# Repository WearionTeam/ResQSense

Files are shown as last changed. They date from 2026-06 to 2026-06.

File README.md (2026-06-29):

 # ResQSense

**ResQSense** is a smart vest project designed to protect those who give everything for us: firefighters. The system monitors vital signs, detects falls, and tracks the user's location in real time, sending all data over radio using **LoRa** technology (essential for scenarios without internet or mobile network coverage).

## Repository Structure

* **Documentation:** Project reports, test logs, and explanations of how the algorithms work (such as Man-Down and PDR).
* **Management:** Project organization and our Gantt chart template for tracking deadlines.
* **Schematics:** Hardware electrical schematics (native KiCad files and PDF versions for direct viewing on GitHub).
* **firmware:** Contains the C++ code. Includes test examples (UWB, vitals reading, etc.) and the final project divided into two parts: the vest (**vest**) and the central hub (**dashboard-tablet**).
* **shared:** Stores the global configuration files (`config.h` and `protocol.h`) that define the hardware pins and the data packet structure.
    * **Important Note:** This folder is only required for the vest's firmware (**vest**). It was created separately and mapped in the `platformio.ini` file to cleanly share definitions, but it is not used in any other project code (such as the dashboard or tablet).

## Main Vest Features

* **Fall Detection (Man-Down):** The IMU (MPU-6050) detects free falls and impacts. If the user remains immobile, it triggers an SOS.
* **Vital Signs:** Heart rate and blood oxygen (SpO2) measurement, along with a fault-tolerant system featuring 3 temperature sensors (TMP117).
* **Hybrid Navigation:** Uses GPS/GNSS, but if the signal is lost (e.g., inside a pavilion), it uses IMU steps to estimate the position.
* **Custom TDMA LoRa Network:** We created a time-slotted LoRa network (TDMA) to allow multiple vests to communicate with the central hub without packet collisions, featuring AES-128 encryption.

## How to run the Vest Code

The software project was developed using **PlatformIO**. To test or upload the code to the board:

1. Install [Visual Studio Code](https://code.visualstudio.com/) and the **PlatformIO** extension.
2. Clone this repository to your PC:
   ```bash
   git clone [https://github.com/WearionTeam/ResQSense.git](https://github.com/WearionTeam/ResQSense.git)```
3. Change your path by making and start VSCode: 
   ```bash
   cd ResQSense/firmware/vest/ResQSenseVest
   code .```
4. Open the **PlatformIO** terminal and type:
   ```bash
   pio run -t upload -e esp32s3usbotg```
   
## How to run the Dashboard Code

The dashboard is built in **Python**. To run it locally:

1. Ensure you have **Python 3** installed in your Rasp.
2. Navigate to the dashboard directory containing the Python scripts
   ```bash
   cd ResQSense/firmware/dashboard```
3. Run the main dashboard interface:
   ```bash
   python3 testedashboard.py```

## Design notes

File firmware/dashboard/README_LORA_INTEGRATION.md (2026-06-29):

# Integracao LoRa com a Dashboard

Esta pasta contem uma copia da interface ligada ao receptor LoRa.

## Como correr na Raspberry

```bash
cd ~/Desktop/int22_lora_integrated
python3 testedashboard.py
```

Por defeito, a dashboard tenta usar LoRa no canal `7` (`868.5 MHz`), que e o canal usado pelo sketch `esp_tablet_fullpacket_test.ino`.

## Variaveis uteis

Forcar simulacao:

```bash
RESQSENSE_FORCE_SIMULATION=1 python3 testedashboard.py
```

Usar LoRa noutro canal:

```bash
RESQSENSE_LORA_CHANNEL=2 python3 testedashboard.py
```

Usar UART em vez de LoRa:

```bash
RESQSENSE_TELEMETRY_TRANSPORT=uart RESQSENSE_FORCE_SIMULATION=0 python3 testedashboard.py
```

## Dependencias na Raspberry

```bash
sudo apt install python3-pycryptodome python3-rpi.gpio python3-spidev
```

O receptor LoRa espera o mesmo wiring usado nos testes:

- `CS` -> `CE0 / GPIO8`
- `RST` -> `GPIO22`
- `DIO0/G0` -> `GPIO25`
- SPI0 normal da Raspberry (`MOSI`, `MISO`, `SCK`)

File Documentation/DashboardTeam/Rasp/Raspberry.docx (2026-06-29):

-1. Identificação e Acesso

- Hardware: Raspberry Pi 3 Model B+.
- Hostname: pee.local
- Credenciais de Acesso:
- Utilizador: pee
  - Password: pee

Aceder a pastas

1. cd /caminho

Executar

2. python3 main.py

Permissões de administrador (sudo)

3. sudo python3 raspberry.py

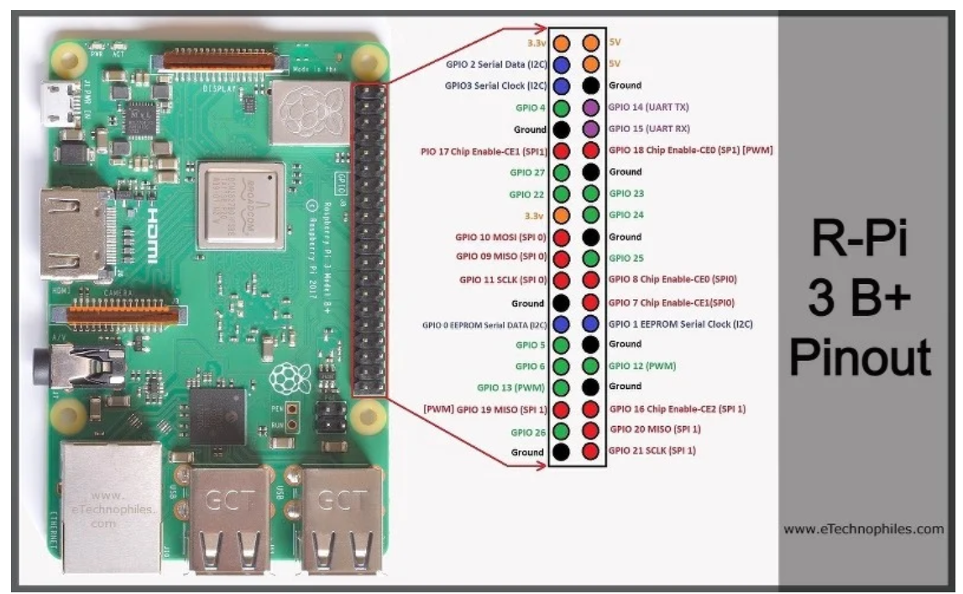
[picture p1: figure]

Pino Físico | Função | Destino / Componente | Nota Técnica
Pino 4 | 5V (VCC) | Display | VCC
Pino 6 | (Gnd) | Display | GND
Pino 1 | 3.3V | Magnetometro | VIN
Pino 9 | (Gnd) | Magnetometro | GND
Pino 3 | Serial Data | Magnetometro | SDA
Pino 5 | Serial Clock | Magnetometro | SCL
Pino 1 | Vin | Lora
Pino 9 | GND | Lora
Pino 22 | G0 | Lora
Pino 23 | SCK | Lora
Pino 21 | MISO | Lora
Pino 19 | MOSI | Lora
Pino 24 | CS | Lora
Pino 17 | RST | Lora

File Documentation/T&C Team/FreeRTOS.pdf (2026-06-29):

# 3Date: 21/04/2026 Tags:

# Lista de Signficados

# FreeRTOS

FreeRTOS providencia um framework para correr várias "tasks" em simultâneo, cada task possui a sua prioridade e horário de execução. Possui ferramentas como "queues" e "semaphores".

# Tasks

# Criar uma Task

# RTOS -> Real-Time Operating System Framework -> Software environment que é reutilizável, funciona como um esqueleto para

aplicações. Possui bibliotecas, APIs e ferramentas para desenvolvimento.

# Tasks -> Funções independentes, cada task com a sua memória alocada e prioridade. Estados

das tasks: Running, Ready, Block ou Suspended.

# Scheduler -> Decide qual das tasks correr baseando-se na prioridade de cada uma. Consegue

interromper uma task de baixa prioridade para correr uma de alta prioridade.
Priorities -> Números mais altos significa maior prioridade.

1º : Declarar uma variável do tipo/class TaskHandle_t que serve como um ponteiro para a task. Usamos a variável para controlar a task (e.g resumir, parar ou apagar a task).
2º : Criar a task. Uma task, como exposto na lista de significados, nada mais é do que uma função, porém têm de obedecer a duas condições : Tem de dar return void; E tem de aceitar um único argumento que poderá ser usado para passar dados para a função.
3º : Para finalizar e usufruir da task, temos de designar uma core especifico para correr a task. Para isto usamos uma função específica -> xTaskCreatePinnedToCore() . Esta função especifica as características da task, a sua função, nome, tamanho da stack, parâmetros, prioridade e o "task handle".

## Criação de Task - Exemplo

/*

Rui Santos & Sara Santos - Random Nerd Tutorials

Complete project details at https://RandomNerdTutorials.com/esp32-freertos-

arduino-tasks/

Permission is hereby granted, free of charge, to any person obtaining a copy of

this software and associated documentation files.

The above copyright notice and this permission notice shall be included in all

copies or substantial portions of the Software.

*/

#define LED_PIN 2

1

2

3

4

5

6

# Resumir e Suspender uma Task

Para o propósito de resumir ou suspender uma task, o FreeRTOS providencia-nos com duas functions :

# Criar e Correr múltiplas Task

A criação para uma ou mais tasks é igual, tirando o número de vezes que tem-se de repetir o processo.
Também podemos criar e correr diversas tasks usando os dois núcleos. Para este fim, precisamos de

# mudar uma das características especificadas quando chamamos a função

xTaskCreatePinnedToCore() . No último campo, especifico do core, basta mudar para o número 0.

// Declare task handle

TaskHandle_t BlinkTaskHandle = NULL;

void BlinkTask(void *parameter) {

for (;;) { // Infinite loop

digitalWrite(LED_PIN, HIGH);

Serial.println("BlinkTask: LED ON");

vTaskDelay(1000 / portTICK_PERIOD_MS); // 1000ms

digitalWrite(LED_PIN, LOW);

Serial.println("BlinkTask: LED OFF");

vTaskDelay(1000 / portTICK_PERIOD_MS);

Serial.print("BlinkTask running on core ");

Serial.println(xPortGetCoreID());
}
}

void setup() {

Serial.begin(115200);

pinMode(LED_PIN, OUTPUT);

xTaskCreatePinnedToCore(

BlinkTask, | // Task function
"BlinkTask", | // Task name
10000, | // Stack size (bytes)
NULL, | // Parameters
1, | // Priority
&BlinkTaskHandle, | // Task handle
1 | // Core 1
);
}

void loop() {

// Empty because FreeRTOS scheduler runs the task
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
vTaskSuspend() : Passamos como argumento a task handle; vTaskResume() : Passamos como argumento a task handle.

# Memória Usada

As tasks do FreeRTOS, na ESP32, usam dois tipos diferentes de memória (em simultâneo): heap e stack; Cada uma destas memórias possui propósitos diferentes.

# Semáforos

Semáforos são ferramentas de sinalização usadas para coordenadar as tasks, são normalmente usados para indicar que um evento ocorreu or que algo está disponível. Semáforos não podem transportar dados, só um sinal para sinalizar que algo aconteceu.

## Tasks em diferentes Cores

void setup() {

Serial.begin(115200);

xTaskCreatePinnedToCore(

Task1, | // Task function
"Task1", | // Task name
10000, | // Stack size (bytes)
NULL, | // Parameters
1, | // Priority
&Task1Handle, | // Task handle
1 | // Core 1
);

xTaskCreatePinnedToCore(

Task2, | // Task function
"Task2", | // Task name
10000, | // Stack size (bytes)
NULL, | // Parameters
1, | // Priority
&Task2Handle, | // Task handle
0 | // Core 0
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
Uso da Stack -> Uma área de memória dedicada para cada task, pode guardar variáveis locais, informação sobre a function call e o estado da task em execução. A stack de cada task é criada ao mesmo tempo que a task, o que por sua vez implica que temos de alocar previamente o espaço

# necessário para executar a task. Existe uma função uxTaskGetStackHighWaterMark() que determina o espaço de memória não usado, daí conseguimos alocar uma stack mais exata ao

fazer algumas iterações.

# Uso da Heap -> A heap é uma "memory pool" conjunta, dentro da SRAM da ESP32. Usada para

memória dinâmica (e.g, task stack, buffers). À semelhança da stack a heap também possui uma

# função com o propósito de determinar o espaço não usado, xPortGetFreeHeapSize()

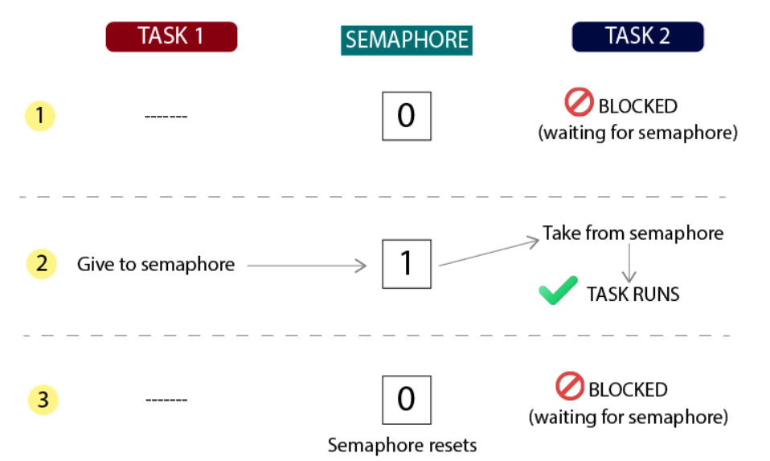
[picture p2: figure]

# Existem dois tipos de semáforos:

# Functions de um semáforo

# Códigos de Exemplo

Semáforo Binário -> Sinaliza um único evento. Serve como ferramenta de sincronização e pode ter valores como 0 (vazio) e 1 (cheio).

# Semáforo de Contagem -> Em vez de só monitorizar um evento, monitoriza N eventos (N sendo

o número de eventos que o utilizador define). E funciona como uma sincronização digital.

# xSemaphoreCreateBinary() -> Cria uma semáforo binário e devolve um handle da classe SemaphoreHandle_t quando sucede na criação do semáforo, ou devolve NULL se não conseguir

criar.

# xSemaphoreCreateCounting() -> Cria uma semáforo de contagem e devolve um handle da classe SemaphoreHandle_t quando sucede na criação do semáforo, ou devolve NULL se não conseguir criar. Para além disto, podemos passar o número máximo de eventos que ele conta (N) como

argumento.

# xSemaphoreTake(semaphore, timeout) -> Usamos esta função dentro de uma task para esperar

ou obter um semáforo. Num semáforo binário se o estado for 1, a tarefa obtem o semáforo e troca o estado para 0, e se o estado for 0, a tarefa espera pelo tempo definido (timeout) pelo semáforo. Por outro lado, num semáforo de contagem, quando o N é maior que 0 ele vai decremetando até chegar a 0, que manda a task esperar.

# xSemaphoreGive() -> Usada dentro de uma task para dar o semáforo a uma outra, fazendo com

que uma possível taks que estivesse à espera, obter o semáforo.

# xSemaphoreGiveISR() -> Mesma coisa que xSemaphoreGive() mas quando é usada numa

interrupt.

## Exemplo Semáforo Binário

/*

Rui Santos & Sara Santos - Random Nerd Tutorials

Complete project details at https://RandomNerdTutorials.com/esp32-freertos-

semaphores-arduino/

Permission is hereby granted, free of charge, to any person obtaining a copy of

this software and associated documentation files.

The above copyright notice and this permission notice shall be included in all

copies or substantial portions of the Software.

*/

#define BUTTON_PIN 23

#define LED1_PIN 2 | // Toggled LED

#define LED2_PIN 4 | // Blinking LED

#define DEBOUNCE_DELAY 200

SemaphoreHandle_t buttonSemaphore = NULL;

volatile uint32_t lastInterruptTime = 0;

void IRAM_ATTR buttonISR() {

uint32_t currentTime = millis();

if (currentTime - lastInterruptTime > DEBOUNCE_DELAY) {

BaseType_t higherPriorityTaskWoken = pdFALSE;

xSemaphoreGiveFromISR(buttonSemaphore, &higherPriorityTaskWoken);

lastInterruptTime = currentTime;

if (higherPriorityTaskWoken) {

portYIELD_FROM_ISR();
}
}
}

void LEDToggleTask(void *parameter) {

pinMode(LED1_PIN, OUTPUT);

bool ledState = false;

## for (;;) {

if (xSemaphoreTake(buttonSemaphore, portMAX_DELAY)) {

ledState = !ledState;

digitalWrite(LED1_PIN, ledState ? HIGH : LOW);

Serial.print("LEDToggleTask: LED1 ");

Serial.println(ledState ? "ON" : "OFF");
}
}
}

void LEDBlinkTask(void *parameter) {

pinMode(LED2_PIN, OUTPUT);

## for (;;) {

digitalWrite(LED2_PIN, HIGH);

Serial.println("LEDBlinkTask: LED2 ON");

vTaskDelay(250 / portTICK_PERIOD_MS);

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
44 digitalWrite(LED2_PIN, LOW);

Serial.println("LEDBlinkTask: LED2 OFF");

vTaskDelay(250 / portTICK_PERIOD_MS);
}
}

void setup() {

Serial.begin(115200);

// Defining the button as an interrupt

pinMode(BUTTON_PIN, INPUT_PULLUP);

attachInterrupt(digitalPinToInterrupt(BUTTON_PIN), buttonISR, FALLING);

buttonSemaphore = xSemaphoreCreateBinary();

if (buttonSemaphore == NULL) {

Serial.println("Failed to create semaphore!");

while (1);
}

xTaskCreatePinnedToCore(

LEDToggleTask, | // Task function
"LEDToggleTask", | // Task name
3000, | // Stack size
NULL, | // Task parameters
2, | // Higher priority
NULL, | // Task handle
1 | // Core ID
);

xTaskCreatePinnedToCore(

LEDBlinkTask, | // Task function
"LEDBlinkTask", | // Task name
3000, | // Stack size
NULL, | // Task parameters
1, | // Medium priority
NULL, | // Task handle
1 | // Core ID
);
}

void loop() {

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
## Exemplo Semáforo de Contagem

/*

Rui Santos & Sara Santos - Random Nerd Tutorials

Complete project details at https://RandomNerdTutorials.com/esp32-freertos-

semaphores-arduino/

1

Permission is hereby granted, free of charge, to any person obtaining a copy of

this software and associated documentation files.

The above copyright notice and this permission notice shall be included in all

copies or substantial portions of the Software.

*/

#define BUTTON_PIN 23

#define LED1_PIN 2 | // Blinking LED

#define LED2_PIN 4 | // Fading LED

#define DEBOUNCE_DELAY 200 // debounce for the pushbutton in milliseconds

#define SEMAPHORE_MAX_COUNT 5

SemaphoreHandle_t buttonSemaphore = NULL;

volatile uint32_t lastInterruptTime = 0;

void IRAM_ATTR buttonISR() {

uint32_t currentTime = millis();

if (currentTime - lastInterruptTime > DEBOUNCE_DELAY) {

BaseType_t higherPriorityTaskWoken = pdFALSE;

if (xSemaphoreGiveFromISR(buttonSemaphore, &higherPriorityTaskWoken) == pdTRUE)
{

Serial.println("buttonISR: Gave semaphore token");

} else {

Serial.println("buttonISR: Semaphore full");
}

lastInterruptTime = currentTime;

if (higherPriorityTaskWoken) {

portYIELD_FROM_ISR();
}
}
}

void LEDBlinkTask(void *parameter) {

pinMode(LED1_PIN, OUTPUT);

## for (;;) {

// Get and print the current semaphore count

UBaseType_t count = uxSemaphoreGetCount(buttonSemaphore);

Serial.print("LEDBlinkTask: Current semaphore count = ");

Serial.println(count);

if (xSemaphoreTake(buttonSemaphore, portMAX_DELAY)) {

Serial.println("LEDBlinkTask: Blinking LED1 for button press");

vTaskDelay(500 / portTICK_PERIOD_MS);

digitalWrite(LED1_PIN, HIGH);

vTaskDelay(1000 / portTICK_PERIOD_MS);

digitalWrite(LED1_PIN, LOW);

vTaskDelay(500 / portTICK_PERIOD_MS);
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
49 void LEDFadeTask(void *parameter) {

pinMode(LED2_PIN, OUTPUT);

## for (;;) {

// Fade up (0 to 255)

for (int duty = 0; duty <= 255; duty += 5) {

analogWrite(LED2_PIN, duty);

if (duty % 50 == 0) { // Print every 10th step

Serial.print("LEDFadeTask: Fading LED2, duty=");

Serial.println(duty);
}

vTaskDelay(50 / portTICK_PERIOD_MS);
}

// Fade down (255 to 0)

for (int duty = 255; duty >= 0; duty -= 5) {

analogWrite(LED2_PIN, duty);

if (duty % 50 == 0 || duty == 255) {

Serial.print("LEDFadeTask: Fading LED2, duty=");

Serial.println(duty);
}

vTaskDelay(50 / portTICK_PERIOD_MS);
}
}
}

void setup() {

Serial.begin(115200); // Higher baud rate

delay(1000);

Serial.println("Starting FreeRTOS: Counting Semaphore");

pinMode(BUTTON_PIN, INPUT_PULLUP);

attachInterrupt(digitalPinToInterrupt(BUTTON_PIN), buttonISR, FALLING);

buttonSemaphore = xSemaphoreCreateCounting(SEMAPHORE_MAX_COUNT, 0);

if (buttonSemaphore == NULL) {

Serial.println("Failed to create semaphore!");

while (1);
}

xTaskCreatePinnedToCore(

LEDBlinkTask, | // Task function
"LEDBlinkTask", | // Task name
3000, | // Stack size
NULL, | // Task parameters
2, | // Higher priority
NULL, | // Task handle
1 | // Core ID
);

xTaskCreatePinnedToCore(

LEDFadeTask, | // Task function
"LEDFadeTask", | // Task name

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
# Queues

Queues são estruturas de dados seguras que permitem diferentes tasks receberem ou enviarem dados umas para as outras, usado para comunicação síncrona dentro de um ambiente multi-task. Também garante que não existem conflitos ou perdas de dados. A queue funciona como uma fila de espera, o primeiro a entrar é o primeiro a ser lido e removido, e os dados que estão na queue não são movidos, ou seja, copiamos a variável, isto permite-nos alterar os dados na task de origem. Para além disto, a queue elimina a necessidade de polling e contém uma espera automática.

# Functions de Queue

# Códigos de Exemplo

3000, | // Stack size
NULL, | // Task parameters
1, | // Lower priority
NULL, | // Task handle
1 | // Core ID
);
}

void loop() {}

109

110

111

112

# xQueueCreate(size, item_size) -> Cria uma queue, onde size é o número de itens/variáveis

que a queue possui e item_size é o tamanho de bytes alocados na heap para cada item. xQueueSend() -> Adiciona dados na queue.

# xQueueSendFromISR() -> Adicionada dados na queue apartir de uma interrupt

xQueueReceive() -> Lê dados dentro da queue, se os tiver.

## Básicos de Queue

/*

Rui Santos & Sara Santos - Random Nerd Tutorials

Complete project details at https://RandomNerdTutorials.com/esp32-freertos-

queues-inter-task-arduino/

Permission is hereby granted, free of charge, to any person obtaining a copy of

this software and associated documentation files.

The above copyright notice and this permission notice shall be included in all

copies or substantial portions of the Software.

*/

#define POT_PIN 15

#define LED_PIN 2

#define PWM_FREQ 5000

#define PWM_RESOLUTION 12 // 12-bit (0–4095)

#define QUEUE_SIZE 5

// Create an handle for the queue

QueueHandle_t potQueue = NULL;

void potTask(void *parameter) {

## for (;;) {

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
uint16_t potValue = analogRead(POT_PIN); | // Read 0–4095
xQueueSend(potQueue, &potValue, portMAX_DELAY); | // Send to queue

Serial.printf("potTask: Sent pot value %u\n", potValue);

vTaskDelay(100 / portTICK_PERIOD_MS); // 100ms
}
}

void LEDBrightnessTask(void *parameter) {

## for (;;) {

uint16_t potValue;

if (xQueueReceive(potQueue, &potValue, portMAX_DELAY)) {

uint16_t brightness = potValue;

ledcWrite(LED_PIN, brightness);

Serial.printf("LEDBrightnessTask: Set brightness %u\n", brightness);
}
}
}

void setup() {

Serial.begin(115200);

// Setup PWM for LED

ledcAttach(LED_PIN, PWM_FREQ, PWM_RESOLUTION);

// Create queue (5 items, each uint16_t)

potQueue = xQueueCreate(QUEUE_SIZE, sizeof(uint16_t));

if (potQueue == NULL) {

Serial.println("Failed to create queue!");

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
## Partilha de dados entre 3 Tasks

/*

Rui Santos & Sara Santos - Random Nerd Tutorials

Complete project details at https://RandomNerdTutorials.com/esp32-freertos-

queues-inter-task-arduino/

Permission is hereby granted, free of charge, to any person obtaining a copy of

this software and associated documentation files.

The above copyright notice and this permission notice shall be included in all

copies or substantial portions of the Software.

*/

#define POT_PIN 15

#define LED_PIN 2

#define PWM_FREQ 5000

#define PWM_RESOLUTION 12 // 12-bit (0–4095)

#define QUEUE_SIZE 5

QueueHandle_t potQueue = NULL;

QueueHandle_t sMonitorQueue = NULL;

void SensorTask(void *parameter) {

## for (;;) {

uint16_t potValue = analogRead(POT_PIN); // Read 0–4095

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
xQueueSend(potQueue, &potValue, portMAX_DELAY); | // Send to queue
xQueueSend(sMonitorQueue, &potValue, portMAX_DELAY); | // Send to queue
vTaskDelay(300 / portTICK_PERIOD_MS); | // 300ms
}
}

void LEDBrightnessTask(void *parameter) {

## for (;;) {

uint16_t potValue;

if (xQueueReceive(potQueue, &potValue, portMAX_DELAY)) {

uint16_t brightness = potValue;

ledcWrite(LED_PIN, brightness);
}
}
}

void SerialLoggerTask(void *parameter) {

## for (;;) {

uint16_t potValue;

if (xQueueReceive(sMonitorQueue, &potValue, portMAX_DELAY)) {

Serial.printf("SerialLoggerTask: Pot value %u at %lu ms\n", potValue,

millis());
}
}
}

void setup() {

Serial.begin(115200);

// Setup PWM for LED

ledcAttach(LED_PIN, PWM_FREQ, PWM_RESOLUTION);

// Create queue (5 items, each uint16_t)

potQueue = xQueueCreate(QUEUE_SIZE, sizeof(uint16_t));

if (potQueue == NULL) {

Serial.println("Failed to create queue!");

while (1);
}

// Create queue (5 items, each uint16_t)

sMonitorQueue = xQueueCreate(QUEUE_SIZE, sizeof(uint16_t));

if (sMonitorQueue == NULL) {

Serial.println("Failed to create queue!");

while (1);
}

// Create tasks with one parameter per line

xTaskCreatePinnedToCore(

SensorTask, | // Task function
"SensorTask", | // Task name
3000, | // Stack size (bytes)
NULL, | // Task parameters

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
# Mutex

Um mutex é um tipo especial de semáforo binário. Ele faz o controlo de acesso a uma fonte/variável comum a dois ou mais taks. O termo "mutex" significa "Mutual Exclusion", funcionando como uma "chave" onde quem tem a chave tem direito a aceder à fonte/variável partilhada. Para usar um mutex, a task tem de ficar com eles, ficando com a chave e quanto a task acaba ele devolve o mutex para outras task. A imagem a seguir, representa como é que duas tasks interagiam quando têm uma source

1, | // Priority
NULL, | // Task handle
1 | // Core ID
);

xTaskCreatePinnedToCore(

LEDBrightnessTask, | // Task function
"LEDBrightnessTask", | // Task name
3000, | // Stack size (bytes)
NULL, | // Task parameters
1, | // Priority
NULL, | // Task handle
1 | // Core ID
);

xTaskCreatePinnedToCore(

SerialLoggerTask, | // Task function
"SerialLoggerTask", | // Task name
3000, | // Stack size (bytes)
NULL, | // Task parameters
1, | // Priority
NULL, | // Task handle
1 | // Core ID
);
}

void loop() {

// Empty
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
# em comum:

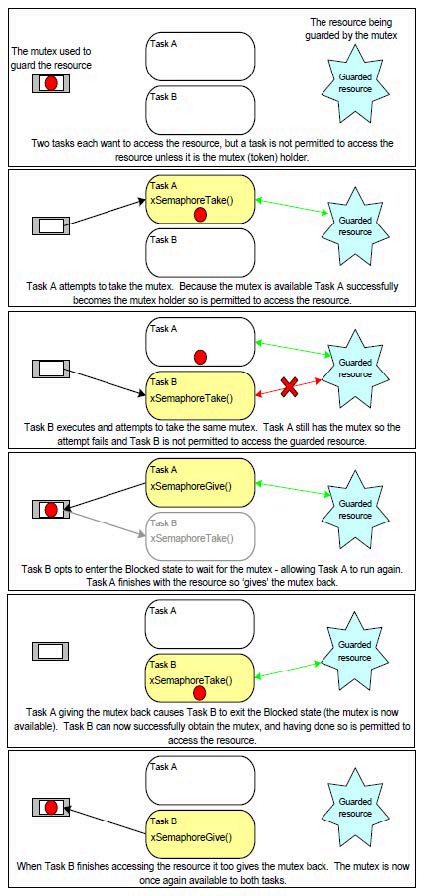
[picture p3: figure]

# Herança de prioridade

Quando uma tarefa de alta prioridade tenta aceder a um recurso que está ocupado por uma de baixa prioridade, o FreeRTOS aplica a herança de prioridade para evitar que o sistema bloqueie. Basicamente, a tarefa que detém o Mutex herda temporariamente a prioridade da tarefa mais alta que está à espera. Isto faz com que a tarefa mais lenta termine o seu trabalho mais depressa, sem ser interrompida por outras, libertando o recurso rapidamente. Assim que o Mutex é entregue, a tarefa volta à sua prioridade normal e a tarefa de alta prioridade assume logo o controlo.

# Functions de um Mutex

# Exemplo

# xSemaphoreCreateMutex() -> Devolve um handle da classe SemaphoreHandle_t quando sucede

na criação do semáforo, ou devolve NULL se não conseguir criar.

# xSemaphoreTake(mutex, timeout) -> Obtem um mutex e ganha acesso ao recurso partilhado

xSemaphoreGive(mutex) -> Para dar o mutex, ou seja, a task que anteriormente o obteve agora "solta" o mutex para outras task acedem ao recurso partilhado.

## Serial Output Mutex

#define MUTEX_TIMEOUT 5000 // 5s timeout

SemaphoreHandle_t serialMutex = NULL;

void Task1(void *parameter) {

## for (;;) {

if (xSemaphoreTake(serialMutex, MUTEX_TIMEOUT)) {

Serial.println("Task1: Logging from Task 1");

vTaskDelay(1000 / portTICK_PERIOD_MS);

Serial.println("Task1: End of log from Task 1");

xSemaphoreGive(serialMutex);
}

vTaskDelay(5000 / portTICK_PERIOD_MS);
}
}

void Task2(void *parameter) {

## for (;;) {

if (xSemaphoreTake(serialMutex, MUTEX_TIMEOUT)) {

Serial.println("Task2: Logging from Task 2");

vTaskDelay(800 / portTICK_PERIOD_MS);

Serial.println("Task2: End of log from Task 2");

xSemaphoreGive(serialMutex);
}

vTaskDelay(3000 / portTICK_PERIOD_MS);
}
}

void setup() {

Serial.begin(115200);

delay(1000);

Serial.println("Starting FreeRTOS");

serialMutex = xSemaphoreCreateMutex();

if (serialMutex == NULL) {

Serial.println("Failed to create mutex!");

while (1);
}

xTaskCreatePinnedToCore(

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
# Referência

# https://randomnerdtutorials.com/esp32-freertos-arduino-tasks/ https://randomnerdtutorials.com/esp32-freertos-semaphores-arduino/ https://randomnerdtutorials.com/esp32-freertos-queues-inter-task-arduino/#more-173794 https://randomnerdtutorials.com/esp32-freertos-mutex-arduino/

Task1, | // Task function
"Task1", | // Task name
3000, | // Stack size
NULL, | // Task parameters
1, | // Priority
NULL, | // Task handle
1 | // Core ID
);

xTaskCreatePinnedToCore(

Task2, | // Task function
"Task2", | // Task name
3000, | // Stack size
NULL, | // Task parameters
2, | // Higher priority
NULL, | // Task handle
1 | // Core ID
);
}

void loop() {

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
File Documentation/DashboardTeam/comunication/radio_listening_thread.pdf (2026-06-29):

# Função radio_listening_thread()

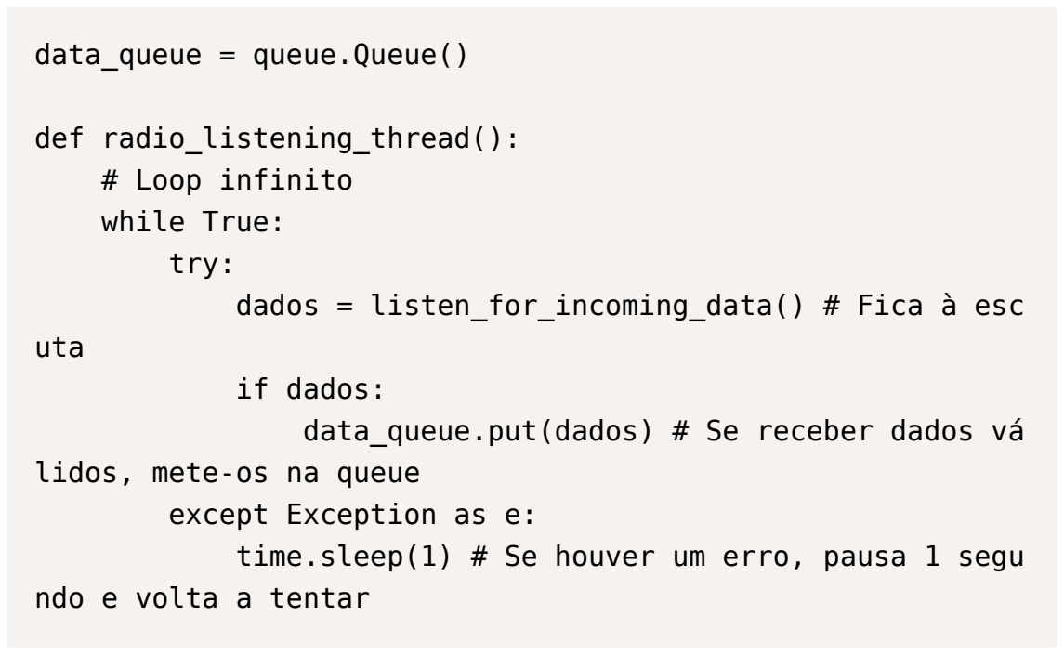
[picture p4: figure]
data_queue = queue.Queue(); def radio_listening_thread(): # Loop infinito while True: try:; uta; if dados:; lidos, mete-os na queue except Exception as e:; ndo e volta a tentar

dados = listen_for_incoming_data() # Fica à esc

data_queue.put(dados) # Se receber dados vá

time.sleep(1) # Se houver um erro, pausa 1 segu

O queue.Queue() é uma lista "Thread-Safe". Isto significa que tu podemos estar a atirar dados lá para dentro, e ao mesmo tempo a retirar dados de lá, e os dados nunca chocam nem se perdem. Se por exemplo o rádio receber 10 pacotes num segundo e o teu ecrã só atualizar a cada 2 segundos, os pacotes ficam aqui guardados, por ordem de chegada.

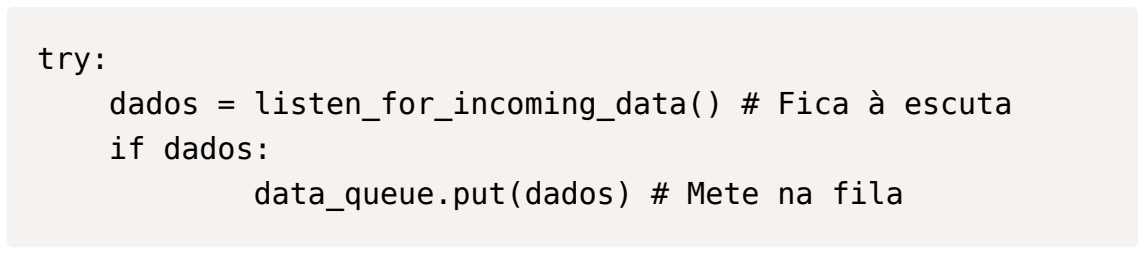
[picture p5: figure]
try:; if dados: data_queue.put(dados) # Mete na fila

dados = listen_for_incoming_data() # Fica à escuta

Função radio_listening_thread() | 1

dados = listen_for_incoming_data(): Chamamos esta função e ficamos à espera de uma resposta (um pacote válido com um dos seguintes tamanhos 15, 7, 4 ou 2 bytes).

if dados: Se receber dados (e não Vazio), avança.

data_queue.put(dados): Guarda tudo traduzido (com a temperatura, o GPS, os BPM) diretamente para dentro do data_queue . Após isto volta para o while True e fica à escuta.

Função radio_listening_thread() | 2

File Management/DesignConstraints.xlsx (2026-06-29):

Cor | Categoria | Constraint | Causa | PxI | P | I | Impacto | Mitigação
 | Geral | Planeamento incompleto | Subestimação de tarefas; Má coordenação; Prazos irrealistas. | 12 | 4 | 3 | Atrasos no projeto e desorientação do grupo. | Reuniões semanais e revisões periódicas do plano. |  | Matriz de Risco 5x5 (PxI):
 | Geral | Especificações do projeto não detalhadas | Interfaces vagas; Pinouts indefinidos; Requisitos ambíguos. | 15 | 3 | 5 | Problemas na integração futura dos módulos. | Definição clara e objetiva de todos as especificações/requisitos. |  |  |  |  | Impacto
 | Geral | Componentes incapazes de completar as tarefas pretendidas | Specs teóricas (datasheet) inferiores à realidade; Requisitos de processamento subestimados; Degradação de performance em carga máxima. | 4 | 1 | 4 | Acréscimo no custo do projeto e atrasos para a criação dos módulos. | Estudar bem os datasheets e realizar testes progressivos. |  |  |  |  | 1 (Pouco) | 2 | 3 | 4 | 5 (Grande)
 | Geral | Aumento do scope | Adição de funcionalidades extra; Má gestão de prioridades. | 12 | 3 | 4 | Aumento da complexidade do projeto e a possibilidade de não o terminar. | Focar em clarear para todos no grupo o MVP a realizar. |  |  | Probabilidade | 1 (Raro) | 1 | 2 | 3 | 4 | 5
 | Geral | Danificação de componentes | Erro de soldadura; Erros e curto-circuitos na montagem. | 8 | 2 | 4 | Invabilizar componentes comprados e necessidade de esperar por substitutos. | Confirmar no datasheet os pinouts dos módulos, verificar montagens e testar o mínimo possível nas placa branca. |  |  |  | 2 | 2 | 4 | 6 | 8 | 10
 | Vest | Medições incorretas dos módulos | Ruído nos sensores; Falta de calibração; Componentes defeituosos. | 6 | 2 | 3 | Fornecimento de medições erradas ao end-user . | Estudar os sensores, testar e produzir algoritmos que evitem os erros de medição. |  |  |  | 3 | 3 | 6 | 9 | 12 | 15
 | Vest | Sobre-aquecimento dos módulos | Dissipação térmica insuficiente; Falta de isolamento térmico do circuito. | 12 | 3 | 4 | Degradação de leitura ou falha. | Apostar em patrocínios que façam o colete com bons materiais. |  |  |  | 4 | 4 | 8 | 12 | 16 | 20
 | Vest | Instabilidade do PPG | Movimento intenso; Perda de contacto com a pele. | 15 | 5 | 3 | Leituras vitais imprecisas. | Produzir algoritmo para contrariar offsets de tensão produzidos pelo movimento. |  |  |  | 5 (Muito Certo) | 5 | 10 | 15 | 20 | 25
 | Vest | Má colocação dos Sensores | Colete largo/desajustado; Sensor desalinhado do corpo. | 2 | 2 | 1 | Leituras vitais imprecisas. | Testar os melhores posicionamentos dos sensores
 | Vest | Definição incorreta dos temporizadores de envio por LoRa | Configuração errada no início de sessão; Violação do duty-cycle (1%);. | 6 | 2 | 3 | Coletes podem enviar mensagens no mesmo instante ou o recetor pode não estar disponivel para receber. | Garantir que ao iniciar uma missão no Tablet exista um envio de pacotes da definição dos temporizadores de envio. Enviar mensagens periódicas a recalibrar temporizadores.
 | Vest | Falha do UWB | Oclusão por corpo/metal; Falta de uma sightline; Reflexões multipath | 9 | 3 | 3 | Perda da redundancia de localização relativa | Esperar um tempo até voltar a tentar reconectar.
 | Vest | Drift dos módulos | Erro matemático de integração; Falta de correção externa. | 4 | 2 | 2 | Localização relativa incorreta. | Desenvolvimento de algoritmos para recalibrar sensores.
 | Vest | Crosstalk no PCB | Pistas digitais/analógicas próximas; Falta de isolamento; Plano de terra deficiente. | 12 | 3 | 4 | Corrupção dos dados dentro dos módulos e enviados. | Desenvolver os PCB seguindo as regras e ter atenção a pistas próximas.
 | Vest | Alertas não previstos não são enviados | Um operacional deslocar um membro ou algo do género não está previsto | 15 | 3 | 5 | Operacional pode estar (a sentir-se) mal e o colete não avisa podendo levar a acidentes | Colocar um tipo de botão no colete para pedir socorro
 | Energia | Autonomia insuficiente | Consumo real > estimado; Bateria degradada. | 12 | 3 | 4 | Sistema desliga-se antes da missão terminar. | Colocar duas baterias para funcionarem em simultâneo, possibilidade de as carregar e ter energia de reserva (p.e. pilhas).
 | Energia | Sobre-aquecimento da bateria | Carga rápida excessiva; Ambiente externo >60ºC; Curto-circuito. | 15 | 3 | 5 | Falha crítica do sistema e segurança do utilizador. | Escolha de baterias resistentes e homologadas.
 | Energia | Disconexão de energia | Vibração mecânica intensa; Conectores sujos/soltos; Impacto físico. | 4 | 1 | 4 | Sistema ficar offline a meio da missão. | Comprar conectores fiáveis.
 | Comms | Perda de pacotes LoRa | Obstáculos densos (betão); Distância excessiva. | 16 | 4 | 4 | Perda de dados críticos. | Desenvolver sistema onde se o recetor não receber um pacote no tempo esperado, manda um pacote a perguntar pela informação.
 | Comms | Latência elevada em alertas | Congestionamento na fila TX; Retransmissões excessivas; Processamento lento. | 15 | 3 | 5 | Alertas atrasados. | Prioridade de pacotes com alertas e otimização do tamanho do pacote.
 | Comms | Saturaçao do canal | Nó que envia repetidamente; Tráfego excessivo na rede; Duty-cycle esgotado. | 12 | 3 | 4 | Perda de mensagens. | Não nos vamos preocupar com isto para o MVP.
 | Comms | Colisão de pacotes | Transmissão simultânea; Falta de sincronização temporal; Rede densa. | 8 | 2 | 4 | Pacotes não chegam ao destino ou contém dados errados. | Definição de tempos de envio para cada nó da rede.
 | Comms | Pacotes com erros | Ruído RF; Sinal fraco (RSSI baixo); Interferência eletromagnética | 6 | 2 | 3 | Mensagens corrompidas ou com informações erradas. | Pacotes com campo de CRC e reenvio da mensagem caso haja a deteção de erros.
 | Comms | Interferências externas | Dispositivos na banda 868MHz; Redes vizinhas; Jamming. | 3 | 1 | 3 | Rede sobrecarregada ou com a impossibilidade de enviar informação. | ? | Not Yet
 | Firmware | Gimball Lock no IMU no SW | Dois eixos do IMU ficam exatamente alinhados e o programa depois não sabe qual deles é que mudou de posição | 12 | 3 | 4 | O colete pode não conseguir determinar se houve um 'Man Down'
 | Firmware | Falha na deteção de alertas críticos | Limiar (threshold) mal definido; Lógica de comparação errada. | 15 | 3 | 5 | Alertas ausentes ou falsos. | Desenvolver cuidadosamente o algoritmo para a deteção de alertas gerais.
 | Firmware | Crashes/ Watchdog Reset | Erro de ponteiro; Divisão por zero; Loop infinito; Stack overflow. | 12 | 3 | 4 | Paragem do sistema. | Revisão e otimização constante do código. Execução de vários testes. Implementação de um Watchdog Timer.
 | Firmware | Overflow do Buffer | Dados chegam mais rápido que o envio; Escrita lenta em memória. | 8 | 2 | 4 | Dados corrompidos. | Configurar o sensor de PPG com base nos tempos de escrita do FIFO.
 | Firmware | Memory Leak | Alocação sem libertação; Fragmentação de Heap; Logs excessivos em RAM. | 6 | 2 | 3 | O sistema funciona bem nos testes curtos, mas bloqueia (crash) após 4-5 horas de missão. | Testes de longa duração e uso de alocação estática de memória.
 | Firmware | Falhas na gestão de prioridades | Interrutpções mal configuradas. | 3 | 1 | 3 | Processamento pouco otimizado. | Otimização do código e planeamento das atividades críticas.
 | Tablet + Database | GUI lenta com muitos eventos | Thread única (bloqueante); Renderização pesada; Sobrecarga CPU. | 12 | 3 | 4 | Atrasos ou paragem na visualização. | Otimização de receção de dados e limitação de FPS
 | Tablet + Database | Sistema não alerta o utilizador | Driver buzzer/ecrã falha; UI bloqueada; Volume inaudível. | 8 | 2 | 4 | O sistema não cumpre com o seu propósito. | ? | Not Yet
 | Tablet + Database | Falha na deteção de alertas críticos | Limiares (thresholds) mal calibrados; Lógica de comparação errada no algoritmo; Filtragem excessiva de dados (mascara eventos reais). | 12 | 3 | 4 | Alertas ausentes ou falsos. | Assegurar a comunicação entre database e o tablet para a realização dos algoritmos de comparação para alertas.
 | Tablet + Database | Perda dos logs | Database offline. | 9 | 3 | 3 | Falta de histórico. | ? | Not Yet
 | Tablet + Database | Dados corrompidos | Erro de serialização; Falha na memória Flash; Ruído no barramento (SPI/I2C). | 8 | 2 | 4 | Histórico inválido. | Utilização de CRC e validação de dados.
 | Tablet + Database | Falha nos dados biométricos de base | Falha Wi-Fi inicial; Database offline; Erro de ID. | 6 | 2 | 3 | Dados relativos errados. | Desenvolver mecanismo que asegura que o tablet consegue os dados necessários para a missão e guardar localmente.
 | Integração | Interferência UWB - LoRa | Harmónicas de frequência; Proximidade na PCB; Falta de blindagem. | 12 | 3 | 4 | Perda de alcance ou precisão. | Separação física dos dois módulos.
 | Integração | Interferência WiFi - LoRa | Antenas fisicamente próximas; Bandas harmónicas. | 12 | 3 | 4 | Perda de alcance de comunicação e dados corrompidos. | Separação física dos dois módulos.
 | Integração | Atrasos no processamento | Código ineficiente; Leitura bloqueante de sensores; Bus lento. | 9 | 3 | 3 | Dados fora do tempo. | ? | Not Yet
 | Integração | Incompatibilidade HW-SW | Driver incorreto; Pinout errado no código; Níveis lógicos (3V3 vs 5V). | 8 | 2 | 4 | Bugs ou falhas de boot | Produzir módulos separados e ir integrando com versões.

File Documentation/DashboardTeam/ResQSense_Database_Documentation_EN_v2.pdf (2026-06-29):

# ResQSense Wearion

## Database Documentation

## Architecture, Schemas, RBAC, Encryption and GDPR

Project | ResQSense Wearion – Firefighter Monitoring System
Version | 2.0 (with RBAC, pgcrypto, SQLCipher and Audit Log)
Date | March 2026
Databases | SQLCipher (Raspberry Pi) + PostgreSQL/pgcrypto (PC)
Encryption | AES-256 (SQLCipher) + PGP (pgcrypto)

# . Table of Contents

### 1. Introduction and Overview 2. Architecture: SQLCipher vs PostgreSQL + pgcrypto

### 2.1 Why SQLCipher on the Raspberry Pi 2.2 Why PostgreSQL + pgcrypto on the PC 2.3 Synchronisation Between the Two Databases

### 3. Complete Table Schema

### 3.1 role 3.2 team_leader 3.3 operator 3.4 session / session_operator 3.5 biometric_data (with encryption) 3.6 location_data (with encryption) 3.7 alert 3.8 audit_log 3.9 failed_login_attempt

### 4. Relationships Between Tables 5. Entity-Relationship (ER) Diagram 6. Class Diagram 7. Roles and Permissions (RBAC)

### 7.1 Application Roles 7.2 PostgreSQL Users 7.3 Permissions Diagram

### 8. GDPR Compliance

### 8.1 GDPR Data Flow 8.2 Encryption: SQLCipher and pgcrypto 8.3 Decryption Functions

### 9. Indexes and Performance 10. Setup and Usage Guide

### 10.1 Raspberry Pi (SQLCipher) 10.2 PC (PostgreSQL + pgcrypto) 10.3 Testing Connectivity 10.4 Audit Log Examples

# 1. Introduction and Overview

ResQSense Wearion is a real-time monitoring system for firefighters in emergency operations. The system collects biometric data (heart rate, oxygenation, temperature) and location data (distance, altitude, GPS) through sensor vests worn by operators.

The data architecture uses two distinct databases with encryption at rest and role-based access control (RBAC):

- SQLCipher on Raspberry Pi 3 Model B – SQLite with full AES-256 encryption, for real-time operational use in the field.
- PostgreSQL + pgcrypto on the central PC – permanent storage with column-level encryption of sensitive data (health and geolocation data).

### What's New in This Version (v2)

RBAC | Roles table with 3 profiles (dev, team_leader, operator) and granular permissions.
SQLCipher | Replacement of SQLite with SQLCipher (AES-256 encryption of the entire DB).
pgcrypto | Column-level encryption in PostgreSQL for sensitive data (BYTEA).
Audit Log | Dedicated table for action traceability (GDPR accountability).
Decryption functions | biometric_data_decrypted() and location_data_decrypted().
PostgreSQL Users | Native DB roles (resqsense_dev, resqsense_leader, resqsense_sync).

# 2. Architecture: SQLCipher vs PostgreSQL + pgcrypto

Raspberry Pi 3 Model B | | PC (Command)
SQLCipher (AES-256 encrypted SQLite) – Real-time data – Local buffer with synced flag – Interface / Dashboard – Full file encryption (.db) | ■ Periodic sync (Python via TCP/IP) synced: 0 → 1 | PostgreSQL + pgcrypto – Full historical data – Sensitive columns encrypted (BYTEA) – Centralised audit log – Native PostgreSQL roles

Figure 1: ResQSense Wearion Data Architecture

## 2.1 Why SQLCipher on the Raspberry Pi

SQLCipher is an SQLite extension that adds transparent AES-256 encryption to the entire database. It was chosen for the Raspberry Pi for the following reasons:

- Full encryption – The entire database (including metadata, WAL and journal) is encrypted with AES-256. If the SD card or device is lost or stolen, the data is protected.
- No server required – Like SQLite, it requires no server process – it is an embedded library. Ideal for the RPi with only 1 GB of RAM.
- Field robustness – Resistant to drops, sudden power loss and vibration. The encrypted .db file handles abrupt failures.
- Offline operation – Continues recording data locally even without connectivity, synchronising when possible.
- Transparency – The application uses the same SQLite API – just set the key with PRAGMA key before operating.
- GDPR compliance – Fulfils Art. 32 of the GDPR (security of processing) with encryption at rest.

'synced' Field –
Synchronisation Mechanism

The tables biometric_data, location_data, alert, audit_log and failed_login_attempt in SQLite contain a synced (0/1) field that does not exist in PostgreSQL. When synced = 0, the record is pending transmission to the PC.

## 2.2 Why PostgreSQL + pgcrypto on the PC

PostgreSQL with the pgcrypto extension offers column-level encryption, allowing only sensitive data to be encrypted while keeping other fields searchable:

- Column-level encryption – Health fields (heart_rate, oxygenation, temperature) and geolocation (lat, long) are stored as BYTEA encrypted with pgp_sym_encrypt.
- Decryption functions – SECURITY DEFINER functions (biometric_data_decrypted, location_data_decrypted) allow querying decrypted data by passing the key as a parameter.
- Native roles – PostgreSQL users (resqsense_dev, resqsense_leader, resqsense_sync) with granular table-level permissions (SELECT, INSERT, UPDATE).
- Scalability – Supports large volumes of historical data from multiple sessions without degradation.
- Concurrency – Multiple users can query data simultaneously without conflicts.
- Centralised audit log – The audit_log table receives records from both local and RPi-synchronised sources.

## 2.3 Synchronisation Between the Two Databases

1. The RPi collects real-time data from the vests and stores it in SQLCipher with synced = 0.
2. Periodically, the sync script queries records with synced = 0.
3. Data is sent to the PC over the internal network (TCP/IP) using the resqsense_sync user.
4. In PostgreSQL, sensitive data is column-encrypted with pgp_sym_encrypt before insertion.
5. After confirmation, the RPi updates the records to synced = 1.

6. A record is created in the PC's audit_log for traceability.

## Direct Comparison

Feature | SQLCipher (Raspberry Pi) | PostgreSQL + pgcrypto (PC)
Function | Operational / Real-time | Permanent storage
Encryption | AES-256 total (entire .db file) | Per column (pgp_sym_encrypt)
Server | No (embedded) | Yes (service)
DB Roles | No (application-level control) | Yes (resqsense_dev, _leader, _sync)
synced field | Yes | No
Encrypted fields | All (total encryption) | heart_rate_enc, oxygenation_enc, temperature_enc, lat_enc, long_enc
Audit log | Local (synchronised) | Centralised
Network access | Local only | TCP/IP (internal network)

# 3. Complete Table Schema

This section describes each table in detail. The schema has been updated with the roles table (RBAC), audit_log, encrypted columns in PostgreSQL, and SQLCipher support on the Raspberry Pi.

## 3.1 role

Defines the system access profiles (RBAC). Each role specifies granular permissions that control what each type of user can do.

Field | Type (PG / SQLite) | Constraints | Description
id | SERIAL / INTEGER | PRIMARY KEY | Profile identifier
name | VARCHAR(50) / TEXT | NOT NULL, UNIQUE | Role name (dev, team_leader, operator)
can_view_biometrics | BOOLEAN / INTEGER | DEFAULT FALSE/0 | Can view biometric data
can_manage_sessions | BOOLEAN / INTEGER | DEFAULT FALSE/0 | Can create/manage sessions
can_manage_operators | BOOLEAN / INTEGER | DEFAULT FALSE/0 | Can manage operators
can_manage_roles | BOOLEAN / INTEGER | DEFAULT FALSE/0 | Can manage roles (dev only)
can_access_database | BOOLEAN / INTEGER | DEFAULT FALSE/0 | Direct DB access (dev only)
description | TEXT | Nullable | Profile description

Pre-defined roles inserted automatically:

ID | Name | Biometrics | Sessions | Operators | Roles | Database
1 | dev | Yes | Yes | Yes | Yes | Yes
2 | team_leader | Yes | Yes | Yes | No | No
3 | operator | No | No | No | No | No

## 3.2 team_leader

Team leaders who authenticate and manage monitoring sessions. Now include role_id and is_active.

Field | Type (PG / SQLite) | Constraints | Description
id | SERIAL / INTEGER | PRIMARY KEY | Unique identifier
name | VARCHAR(100) / TEXT | NOT NULL | Full name
pin_hash | VARCHAR(255) / TEXT | NOT NULL | PIN hash (never plain text)
role_id | INTEGER | NOT NULL, FK, DEFAULT 2 | Assigned profile (default: team_leader)
is_active | BOOLEAN / INTEGER | DEFAULT TRUE/1 | Whether the user is active
created_at | TIMESTAMP | DEFAULT NOW() | Creation date (PostgreSQL only)

Foreign keys: role_id → role(id)

## 3.3 operator

Firefighters equipped with sensor vests. Now include role_id.

Field | Type (PG / SQLite) | Constraints | Description
id | SERIAL / INTEGER | PRIMARY KEY | Unique identifier
name | VARCHAR(100) / TEXT | NOT NULL | Full name
vest_id | VARCHAR(50) / TEXT | UNIQUE, NOT NULL | Assigned vest ID
is_alerting | BOOLEAN / INTEGER | DEFAULT FALSE/0 | In alert state
baseline_heart_rate | INTEGER | Nullable | Baseline heart rate (bpm)
baseline_temperature | FLOAT / REAL | Nullable | Baseline temperature (°C)
baseline_oxygenation | INTEGER | Nullable | Baseline oxygenation (%)
role_id | INTEGER | NOT NULL, FK, DEFAULT 3 | Profile (default: operator)
created_at | TIMESTAMP | DEFAULT NOW() | Creation date (PostgreSQL only)

Foreign keys: role_id → role(id)

## 3.4 session and session_operator

Monitoring session and associative table of operators per session. Structure unchanged from v1. session:

Field | Type (PG / SQLite) | Constraints | Description
session_id | VARCHAR(100) / TEXT | PRIMARY KEY | Unique identifier (UUID)
leader_id | INTEGER | NOT NULL, FK | Team leader who initiated it
started_at | TIMESTAMP / TEXT | DEFAULT NOW() | Session start
ended_at | TIMESTAMP / TEXT | Nullable | End (NULL = active)

session_operator:

Field | Type (PG / SQLite) | Constraints | Description
session_id | VARCHAR(100) / TEXT | PK composite, FK | Session ID
operator_id | INTEGER | PK composite, FK | Operator ID
joined_at | TIMESTAMP / TEXT | DEFAULT NOW() | When they joined the session

## 3.5 biometric_data (with encryption)

Biometric data from the sensors. In PostgreSQL, health columns are encrypted with pgcrypto (BYTEA instead of INTEGER/FLOAT). In SQLite, encryption is applied at the entire DB level by SQLCipher.

Critical Difference: Column
Names

In PostgreSQL, encrypted fields have the _enc suffix: heart_rate_enc, oxygenation_enc, temperature_enc (BYTEA type).
In SQLite, fields keep their original names: heart_rate, oxygenation, temperature (INTEGER/REAL) because encryption is total.

Field | PostgreSQL Type | SQLite Type | Description
id | SERIAL PK | INTEGER PK AUTO | Unique identifier
operator_id | INTEGER NOT NULL FK | INTEGER NOT NULL FK | Monitored operator
session_id | VARCHAR(100) FK | TEXT FK | Active session
heart_rate_enc / heart_rate | BYTEA (encrypted) | INTEGER | Heart rate (bpm)
oxygenation_enc / oxygenation | BYTEA (encrypted) | INTEGER | O2 saturation (%)
temperature_enc / temperature | BYTEA (encrypted) | REAL | Body temperature (°C)
processing_delay_sec | INTEGER | INTEGER | Processing delay (s)
recorded_at | TIMESTAMP NOT NULL | TEXT DEFAULT | When recorded by sensor
received_at | TIMESTAMP DEFAULT | – (n/a) | Reception at server
synced | – (n/a) | INTEGER DEFAULT 0 | Synchronisation state

## 3.6 location_data (with encryption)

Operator location data. In PostgreSQL, GPS coordinates are encrypted.

Field | PostgreSQL Type | SQLite Type | Description
id | SERIAL PK | INTEGER PK AUTO | Unique identifier
operator_id | INTEGER NOT NULL FK | INTEGER NOT NULL FK | Operator
session_id | VARCHAR(100) FK | TEXT FK | Session
distance | FLOAT | REAL | Distance from reference point (m)
height | FLOAT | REAL | Altitude (m)
lat_enc / lat | BYTEA (encrypted) | REAL | GPS latitude
long_enc / long | BYTEA (encrypted) | REAL | GPS longitude
recorded_at | TIMESTAMP NOT NULL | TEXT DEFAULT | When recorded
received_at | TIMESTAMP DEFAULT | – (n/a) | Reception at server
synced | – (n/a) | INTEGER DEFAULT 0 | Synchronisation

## 3.7 alert

Automatically generated alerts: Man Down, tachycardia, fall, abnormal temperature, etc.

Field | Type (PG / SQLite) | Constraints | Description
id | SERIAL / INTEGER | PK, AUTOINCREMENT | Identifier

Field | Type (PG / SQLite) | Constraints | Description
operator_id | INTEGER | NOT NULL, FK | Operator who triggered the alert
session_id | VARCHAR(100) / TEXT | NOT NULL, FK | Session in which it occurred
timestamp | TIMESTAMP / TEXT | NOT NULL / DEFAULT | Moment of alert
description | TEXT | NOT NULL | Description (e.g. 'Man Down')
synced | – / INTEGER | DEFAULT 0 (SQLite only) | Synchronisation

## 3.8 audit_log (NEW)

Audit table for traceability (GDPR accountability). Records all critical actions without exposing health data. Each record includes the active role at the time of the action.

Field | Type (PG / SQLite) | Constraints | Description
id | SERIAL / INTEGER | PK, AUTOINCREMENT | Identifier
user_id | INTEGER | Nullable | User who performed the action
role_id | INTEGER | FK → role(id) | Active profile at the time
action | VARCHAR(200) / TEXT | NOT NULL | Action (e.g. LOGIN_SUCCESS, SESSION_START)
target_table | VARCHAR(100) / TEXT | Nullable | Affected table
target_id | VARCHAR(100) / TEXT | Nullable | Affected record ID
ip_address | VARCHAR(45) | Nullable | Source IP (PostgreSQL only)
timestamp | TIMESTAMP / TEXT | DEFAULT NOW() | Date and time of action
synced | – / INTEGER | DEFAULT 0 (SQLite only) | Synchronisation

Examples of recorded actions:
- LOGIN_SUCCESS, LOGIN_FAILED – authentication
- SESSION_START, SESSION_END – session management
- OPERATOR_ADDED, OPERATOR_REMOVED – operator management
- BIOMETRIC_VIEWED – query of sensitive data
- ALERT_CREATED – alert generation

## 3.9 failed_login_attempt

Failed login attempts for security and auditing purposes.

Field | Type (PG / SQLite) | Constraints | Description
id | SERIAL / INTEGER | PK | Identifier
leader_id | INTEGER | Nullable | Target leader (if identifiable)
attempted_at | TIMESTAMP / TEXT | NOT NULL / DEFAULT | Date and time
ip_address | VARCHAR(45) | Nullable (PostgreSQL only) | Source IP

Field | Type (PG / SQLite) | Constraints | Description
synced | – / INTEGER | DEFAULT 0 (SQLite only) | Synchronisation

# 4. Relationships Between Tables

Source Table | Field | Target Table | Relationship
team_leader | role_id | role(id) | N:1 – Many leaders per role
operator | role_id | role(id) | N:1 – Many operators per role
session | leader_id | team_leader(id) | N:1 – Many sessions per leader
session_operator | session_id | session(session_id) | N:M – Associative table
session_operator | operator_id | operator(id) | N:M – Associative table
biometric_data | operator_id | operator(id) | N:1 – Many records per operator
biometric_data | session_id | session(session_id) | N:1 – Many records per session
location_data | operator_id | operator(id) | N:1 – Many records per operator
location_data | session_id | session(session_id) | N:1 – Many records per session
alert | operator_id | operator(id) | N:1 – Many alerts per operator
alert | session_id | session(session_id) | N:1 – Many alerts per session
audit_log | role_id | role(id) | N:1 – Contextualises access
failed_login_attempt | leader_id | team_leader(id) | N:1 (implicit)

## Summary of Cardinalities

- One Role can be assigned to many Team Leaders and Operators (1:N).
- One Team Leader can start many sessions (1:N).
- Sessions and operators have an M:N relationship via session_operator.
- Each operator generates many biometric, location and alert records (1:N).
- The Audit Log references roles to contextualise the access level of each action.

# 5. Entity-Relationship (ER) Diagram

The updated ER diagram includes the role (RBAC) and audit_log tables, as well as encrypted columns in PostgreSQL. Relationships follow the Mermaid schema defined in the project.

Entity A | Entity B | Cardinality | Description
role | team_leader | 1:N | Assigns permissions to the leader
role | operator | 1:N | Assigns permissions to the operator
role | audit_log | 1:N | Contextualises access level
team_leader | session | 1:N | Starts sessions
team_leader | failed_login_attempt | 1:N | Records failed attempts
session | session_operator | 1:N | Contains operators
operator | session_operator | 1:N | Participates in sessions
operator | biometric_data | 1:N | Generates biometric data
operator | location_data | 1:N | Generates location data
operator | alert | 1:N | Triggers alerts
session | biometric_data | 1:N | Groups biometric data
session | location_data | 1:N | Groups location data
session | alert | 1:N | Groups alerts

## Main Data Flow

- Team Leader authenticates (pin_hash) → audit_log records LOGIN_SUCCESS.
- Team Leader creates Session → audit_log records SESSION_START.
- Operators are added (session_operator) → audit_log records OPERATOR_ADDED.
- Vests send data → biometric_data + location_data (encrypted in PG).
- System detects anomalies → alert (Man Down, tachycardia, etc.).
- Team Leader ends session (ended_at) → audit_log records SESSION_END.
- Sync sends data from RPi to PC → audit_log records receipt.

# 6. Class Diagram

The UML class diagram shows how database entities map to application classes, including controllers and services.

Figure 2: UML Class Diagram of ResQSense Wearion (Refer to the original document or project repository for the full UML diagram graphic.)

Class | Responsibility
AuthenticationManager | Authenticates team leaders (PIN) and firefighters (vest ID). Records failed attempts and actions in the audit_log.
DashboardController | Main controller. Manages the active session, adds/removes operators, displays details.
Database (Service) | Data access service: findUserByID, findVestByID, getOperatorProfile.
Role (NEW) | RBAC access profile with granular permissions (can_view_biometrics, can_manage_sessions, etc.).
TeamLeader | Team leader with ID, name, pin_hash and role_id.
Operator | Firefighter with identification data, vest, baselines and role_id.
Session | Monitoring session with methods addFirefighterToTeam and createAlert.
BiometricData | Biometric data: heart_rate, oxygenation, temperature (encrypted in PG).
Location | Location data: distance, height, lat, long (GPS encrypted in PG).
Alert | Alert with timestamp, description and operator_id.
AuditLog (NEW) | Audit record: user_id, role_id, action, target, timestamp.

# 7. Roles and Permissions (RBAC)

The system implements role-based access control (RBAC) at two levels: application-level (role table) and database-level (PostgreSQL users). This follows the principle of least privilege required by the GDPR.

## 7.1 Application Roles

Role | Biometrics | Sessions | Operators | Roles | DB | Description
dev (Dev team) | Yes | Yes | Yes | Yes | Yes | Full access. Can modify DB structure, manage roles and view all data.
team_leader (Team lead) | Yes | Yes | Yes | No | No | Manages sessions, adds/removes firefighters, views biometric data and alerts.
operator (Firefighter) | No | No | No | No | No | Can only view their own basic data. No access to health data or management.

## 7.2 PostgreSQL Users

PG User | Corresponding Role | Permissions | Purpose
resqsense_dev | dev | ALL PRIVILEGES | Full access to all tables and sequences. Can modify structure.
resqsense_leader | team_leader | SELECT, INSERT, UPDATE on operational tables; SELECT on data; INSERT on audit_log | Day-to-day operations. Cannot delete data.
resqsense_sync | – (sync) | INSERT on data and audit_log; SELECT on reference tables | Used by RPi to send data. Insert only, no modification.

Dual Security Layer

Access control operates at two layers: the application checks the user's role before executing actions (role table), and PostgreSQL enforces additional restrictions at the database level (GRANT/REVOKE). Even if the application has a vulnerability, PostgreSQL prevents unauthorised operations.

## 7.3 Tables Accessible by Role

Table | dev | team_leader | operator
role | ALL | SELECT | –
team_leader | SELECT, INSERT, UPDATE | SELECT, INSERT, UPDATE | –
operator | SELECT, INSERT, UPDATE | SELECT, INSERT, UPDATE | SELECT (own)
session | ALL | SELECT, INSERT, UPDATE | –

Table | dev | team_leader | operator
session_operator | ALL | SELECT, INSERT, UPDATE | –
biometric_data | ALL | SELECT | –
location_data | ALL | SELECT | –
alert | ALL | SELECT, INSERT, UPDATE | –
audit_log | ALL | INSERT | –
failed_login_attempt | ALL | INSERT | –

# 8. GDPR Compliance

The processing of personal and sensitive data in ResQSense Wearion follows the principles of the General Data Protection Regulation (GDPR).

## 8.1 GDPR Data Flow

1. Vest / Sensor | Generates BiometricData and Location data transmitted to the Raspberry Pi.
2. Raspberry Pi | Receives the data and checks whether an active session exists.
3. Active session? | If no active session, data is immediately discarded (ignored).
4. GDPR Check | Legal basis: Vital Interest (Art. 6(1)(d) and Art. 9(2)(c)) – protection of firefighters' lives.
5. Minimisation | Filter only the variables defined in the BiometricData and Location classes. No unnecessary data collected (Art. 5(1)(c)).
6. Pseudonymisation | Operator.id is separated from health and geolocation data, reducing re-identification risk (Art. 4(5)).
7. Encryption at Rest | SQLCipher encrypts the entire database with AES-256 (Art. 32).
8. Local Storage | Data stored in SQLite with synced=0 flag. Interface displays real-time data.
9. Local Audit Log | Action recorded without exposing health metrics.
10. Synchronisation | When network is available, the sync script sends records with synced=0 to the PC.
11. pgcrypto (PC) | Sensitive columns are individually encrypted with pgp_sym_encrypt before insertion into PostgreSQL.
12. Permanent Storage | PostgreSQL stores the full history with column-encrypted data.
13. Central Audit Log | Data reception recorded in the centralised audit_log.
14. synced=1 Marking | On the RPi, synchronised records are marked as synced=1.

## 8.2 Encryption: SQLCipher and pgcrypto

Aspect | SQLCipher (Raspberry Pi) | pgcrypto (PostgreSQL)
Encryption type | Total (entire .db file) | Per column (BYTEA fields)
Algorithm | AES-256-CBC | PGP symmetric (AES)
Encrypted fields | All (transparent) | heart_rate_enc, oxygenation_enc, temperature_enc, lat_enc, long_enc
Key | PRAGMA key on open | Parameter in pgp_sym_encrypt/decrypt functions
Key management | Environment variable / .env | Environment variable / .env
Performance | Minimal (transparent) | Overhead on encryption/decryption per query
Searchability | Fields normally searchable | Encrypted fields not directly searchable

## 8.3 Decryption Functions (PostgreSQL)

The PostgreSQL schema includes SECURITY DEFINER functions to decrypt data in a controlled manner: biometric_data_decrypted(encryption_key TEXT)
Returns all biometric data with decrypted health fields. Receives the encryption key as a parameter. location_data_decrypted(encryption_key TEXT)
Returns all location data with lat and long decrypted.

Usage example:

-- Query decrypted biometric data
SELECT * FROM biometric_data_decrypted('SECRET_KEY');

-- Insert encrypted data
INSERT INTO biometric_data (operator_id, session_id, heart_rate_enc, oxygenation_enc, temperature_enc, processing_delay_sec, recorded_at)
VALUES (1, 'session_001',
pgp_sym_encrypt('90', 'SECRET_KEY'), pgp_sym_encrypt('97', 'SECRET_KEY'), pgp_sym_encrypt('37.2', 'SECRET_KEY'), 1, '2025-03-18 16:35:00');

## GDPR Principles Applied

GDPR Principle | Implementation in the System
Legal basis (Art. 6) | Vital interest – protection of firefighters' lives
Minimisation (Art. 5(1)(c)) | Only strictly necessary variables in the classes
Pseudonymisation (Art. 4(5)) | operator_id separated from health and geolocation data
Encryption (Art. 32) | SQLCipher (AES-256 total) + pgcrypto (per column)
Access control (Art. 32) | RBAC with 3 roles + native PostgreSQL users
Accountability (Art. 5(2)) | audit_log with user_id, role_id, action and timestamp
Retention limitation (Art. 5(1)(e)) | Data on RPi synchronised and periodically purged

# 9. Indexes and Performance

## PostgreSQL Indexes

Index | Table | Columns | Purpose
idx_biometric_operator_time | biometric_data | operator_id, recorded_at | Biometric data by operator/time
idx_biometric_session | biometric_data | session_id | Filter by session
idx_location_operator_time | location_data | operator_id, recorded_at | Location by operator/time
idx_location_session | location_data | session_id | Filter by session
idx_alert_session | alert | session_id, timestamp | Alerts by session
idx_alert_operator | alert | operator_id | Alerts by operator
idx_session_leader | session | leader_id | Sessions by leader
idx_audit_user | audit_log | user_id, timestamp | Actions by user
idx_audit_action | audit_log | action, timestamp | Actions by type
idx_team_leader_role | team_leader | role_id | Leaders by role
idx_operator_role | operator | role_id | Operators by role

## Additional SQLite Indexes (Synchronisation)

Index | Table | Column | Purpose
idx_biometric_synced | biometric_data | synced | Records pending sync
idx_location_synced | location_data | synced | Locations pending sync
idx_alert_synced | alert | synced | Alerts pending sync
idx_audit_synced | audit_log | synced | Audit logs pending sync

# 10. Setup and Usage Guide

## 10.1 Raspberry Pi (SQLCipher)

Install SQLCipher:

sudo apt update && sudo apt upgrade -y
sudo apt install sqlcipher libsqlcipher-dev -y sqlcipher --version
Install Python dependency:

pip3 install pysqlcipher3
# If it fails, install build dependencies:

sudo apt install build-essential libsqlcipher-dev python3-dev -y pip3 install pysqlcipher3
Create the encrypted database:

mkdir -p ~/resqsense && cd ~/resqsense sqlcipher resqsense.db
-- Inside SQLCipher:
PRAGMA key = 'SET_ENCRYPTION_KEY_HERE'; .read sqlite_schema_rpi.sql
.tables
.quit
Access from Python:

from pysqlcipher3 import dbapi2 as sqlite conn = sqlite.connect('resqsense.db') conn.execute("PRAGMA key = 'KEY_HERE'") cursor = conn.execute("SELECT * FROM role") for row in cursor:
print(row)
conn.close()

Security Verification

To confirm that encryption works, try opening with regular sqlite3: sqlite3 resqsense.db ".tables" should return "Error: file is not a database". Only sqlcipher with the correct key can open the file.

## 10.2 PC (PostgreSQL + pgcrypto)

Install PostgreSQL (Linux):

sudo apt update
sudo apt install postgresql postgresql-contrib -y sudo systemctl start postgresql
sudo systemctl enable postgresql
Create database and users:

sudo -u postgres psql
CREATE DATABASE resqsense;
CREATE USER resqsense_dev WITH PASSWORD 'CHANGE_DEV_PASSWORD'; CREATE USER resqsense_leader WITH PASSWORD 'CHANGE_LEADER_PASSWORD'; CREATE USER resqsense_sync WITH PASSWORD 'CHANGE_SYNC_PASSWORD'; GRANT ALL PRIVILEGES ON DATABASE resqsense TO resqsense_dev;
GRANT CONNECT ON DATABASE resqsense TO resqsense_leader;
GRANT CONNECT ON DATABASE resqsense TO resqsense_sync;
\q
Run the schema and assign permissions:

psql -U resqsense_dev -d resqsense -f postgresql_schema_pc.sql # Assign permissions by role:

psql -U resqsense_dev -d resqsense
GRANT SELECT, INSERT, UPDATE ON team_leader, operator,
session, session_operator, alert TO resqsense_leader;
GRANT SELECT ON biometric_data, location_data, role TO resqsense_leader; GRANT INSERT ON audit_log, failed_login_attempt TO resqsense_leader; GRANT USAGE ON ALL SEQUENCES IN SCHEMA public TO resqsense_leader; GRANT INSERT ON biometric_data, location_data, alert,
audit_log, session, session_operator TO resqsense_sync;
GRANT SELECT ON role, operator, team_leader, session TO resqsense_sync; GRANT USAGE ON ALL SEQUENCES IN SCHEMA public TO resqsense_sync;
Configure internal network access:

Edit postgresql.conf: listen_addresses = '*'
Edit pg_hba.conf and add:
host resqsense resqsense_dev 192.168.1.0/24 md5 host resqsense resqsense_leader 192.168.1.0/24 md5 host resqsense resqsense_sync 192.168.1.0/24 md5 Restart: sudo systemctl restart postgresql

## 10.3 Testing Connectivity

# On the Raspberry Pi:

sudo apt install postgresql-client -y
psql -h 192.168.1.XXX -U resqsense_sync -d resqsense -c "SELECT 1;"

## 10.4 Audit Log Examples

In the Python application, log actions as follows:

def log_action(conn, user_id, role_id, action, target_table=None, target_id=None):
conn.execute(
"""INSERT INTO audit_log
(user_id, role_id, action, target_table, target_id) VALUES (?, ?, ?, ?, ?)""",
(user_id, role_id, action, target_table, target_id)
)
conn.commit()

# Examples:

log_action(conn, 1, 2, 'LOGIN_SUCCESS', 'team_leader', '1') log_action(conn, 1, 2, 'SESSION_START', 'session', 'session_001') log_action(conn, 1, 2, 'OPERATOR_ADDED', 'session_operator', 'op_5') log_action(conn, 1, 2, 'BIOMETRIC_VIEWED', 'biometric_data', 'op_5') log_action(conn, 1, 2, 'SESSION_END', 'session', 'session_001')

### Final Security Notes

Encryption keys | Store in environment variables or .env file, NEVER in source code.
Passwords | Change ALL example passwords before using in production.
Internal network | Adjust the 192.168.1.0/24 range to match your actual network.
PostgreSQL backup | Take regular backups with pg_dump (data remains encrypted).
RPi SSD | Use an SSD or USB drive instead of SD card for greater durability.
Data retention | Define a data deletion policy (e.g. annual CRON job).

ResQSense Wearion – Database Documentation v2.0 – March 2026

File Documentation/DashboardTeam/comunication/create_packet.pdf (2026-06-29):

# Função create_sync_packet():

def create_sync_packet(novo_vest_id, target_net_id, mac_add ress_int, data_ch, ctrl_ch):
# Constrói o pacote de SYNC, junta os bits (Operadores << e |)

net_id = 0b000
byte0 = (net_id << 5) | (novo_vest_id & 0x1F)
opcode = 0b0011 # Opcode 3 significa: "Configuração de Rede"
byte1 = (opcode << 4) | (0b0 << 3) | (target_net_id & 0
x07)
mac_bytes = struct.pack('>I', mac_address_int) # Empaco ta o MAC Address em 4 bytes (Big-Endian)
byte6 = ((data_ch & 0x07) << 5) | (0b0 << 4) | ((ctrl_c
h & 0x07) << 1) | 0b0
return bytes([byte0, byte1]) + mac_bytes + bytes([byte 6])
byte0 = (net_id << 5) | (novo_vest_id & 0x1F)

novo_vest_id & 0x1F: O 0x1F em binário é 0001 1111 (5 bits a 1). Isto é uma máscara de segurança, para garantirmos que qualquer que seja o ID dado ao colete, ele corta sempre o número para caber apenas em 5 bits.

net_id << 5: O NetID tem 3 bits (ex: 000). O comando << 5 empurra esses 3 bits para a esquerda, e adiciona 5 zeros à direita. Fica com algo
tipo: 000x xxxx.

Comando (|): Junta tudo para ficarmos com algo do tipo [3 bits de NetID] [5 bits de VestID].

opcode = 0b0011
byte1 = (opcode << 4) | (0b0 << 3) | (target_net_id & 0
Função create_sync_packet(): | 1

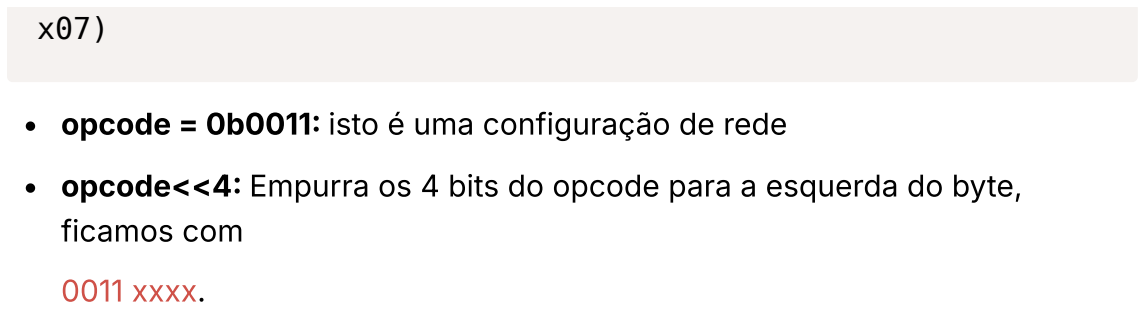
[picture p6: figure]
ficamos com; 0011 xxxx.

opcode = 0b0011: isto é uma configuração de rede

opcode<<4: Empurra os 4 bits do opcode para a esquerda do byte,

0b0<<3: Deixa 1 bit a zero na posição 3.

target_net_id & 0x07: 0x07 em binário é 0000 0111. Garantimos que a rede de destino cabe me 3 bits.

Comando (|): Ficamos com [4 bits Opcode] [1 bit zero] [3 bits TargetNetID].

mac_bytes = struct.pack('>I', mac_address_int)

O MAC Address é um número grande (32 bits). Em vez de estar a fazer a matemática “à mão”, ao usar o struct.pack('>I', ...), convertemos logo esse número grande em 4 bytes separados e já ordenados em Big-Endian.

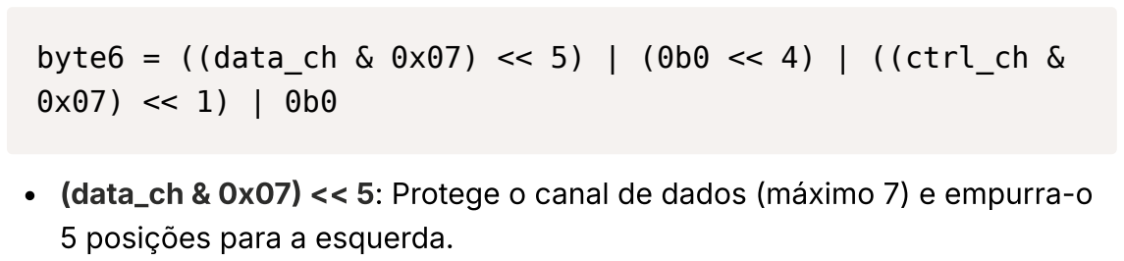
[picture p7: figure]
5 posições para a esquerda.

byte6 = ((data_ch & 0x07) << 5) | (0b0 << 4) | ((ctrl_ch &

(data_ch & 0x07) << 5: Protege o canal de dados (máximo 7) e empurra-o

0b0 << 4: Põe um bit a 0 no meio.

(ctrl_ch & 0x07) << 1: Protege o canal de controlo e empurra-o 1 posição para a esquerda.

| 0b0: Cola um bit a zero no fim (na posição 0).

Ficamos com [3 bits Data Ch] [1 bit 0] [3 bits Ctrl Ch] [1 bit 0].

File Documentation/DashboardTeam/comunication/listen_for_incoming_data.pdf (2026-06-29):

# Função listen_for_incoming_data()

def listen_for_incoming_data(): global memoria_gps

packet = hardware_receive(timeout=0.1, max_bytes=15)

if packet is not None:
# Para testar COM encriptação, usar a linha de baix o:

# decrypted_packet = decrypt_aes_ctr(packet)

# Para testar SEM encriptação, usar a linha de baix o:

decrypted_packet = packet

# Mede o tamanho exato do pacote para saber para on de o encaminhar

tamanho = len(decrypted_packet)

if tamanho == 15:
dados = unpack_telemetria_completa(decrypted_pa cket)
if dados:
vest_id = dados['vest_id']

lat_graus_calc = dados['lat_raw'] // 100000 00
lat_min_calc = abs(dados['lat_raw']) % 1000 0000
lon_graus_calc = dados['lon_raw'] // 100000 00
lon_min_calc = abs(dados['lon_raw']) % 1000
Função listen_for_incoming_data() | 1

0000

memoria_gps[vest_id] = {
'lat_graus': lat_graus_calc, 'lat_min': lat_min_calc,
'lon_graus': lon_graus_calc, 'lon_min': lon_min_calc
}

print(f"[Colete {vest_id}] Trama Completa |
BPM: {dados['bpm']} | Temp: {dados['temperature']:.2f}ºC")
return dados

elif tamanho == 7:

vest_id = decrypted_packet[0] & 0x1F

lat_min_novo, lon_min_novo = struct.unpack('>H H', decrypted_packet[1:5])

if vest_id in memoria_gps:
estado = memoria_gps[vest_id]

limite_superior = 9000000 # Perto de 10 mil hões
limite_inferior = 1000000 # Perto de zero

# Lógica de Rollover da Latitude:

# Se estava num valor alto e caiu para um m uito baixo, andou 1 Grau para a frente if estado['lat_min'] > limite_superior and lat_min_novo < limite_inferior: estado['lat_graus'] += 1

# Se estava num valor baixo e saltou para u m muito alto, andou 1 Grau para trás elif estado['lat_min'] < limite_inferior an d lat_min_novo > limite_superior: estado['lat_graus'] -= 1

estado['lat_min'] = lat_min_novo # Atualiza os decimais novos

# Repete a Lógica de Rollover para a Longit ude

if estado['lon_min'] > limite_superior and lon_min_novo < limite_inferior: estado['lon_graus'] += 1
elif estado['lon_min'] < limite_inferior an d lon_min_novo > limite_superior: estado['lon_graus'] -= 1
estado['lon_min'] = lon_min_novo

print(f"[GPS DELTA] Colete {vest_id} -> {es tado['lat_graus']}.{estado['lat_min']}")

return {
"tipo": "DELTA_GPS",
"vest_id": vest_id,
"lat": f"{estado['lat_graus']}.{estado ['lat_min']}",
"lon": f"{estado['lon_graus']}.{estado ['lon_min']}"
}

elif tamanho == 4:

vest_id = decrypted_packet[0] & 0x1F flags = decrypted_packet[1]

sos = bool((flags >> 6) & 0x01)
md = bool((flags >> 5) & 0x01)

if sos or md:
tipo = "SOS" if sos else "MAN DOWN" print(f"!!! ALERTA CRÍTICO: Colete {vest_i d} em {tipo} !!!")

return {
"tipo": "ALERTA",
"vest_id": vest_id,
"sos": sos,
"man_down": md
}

elif tamanho == 2:
vest_id = decrypted_packet[0] & 0x1F
opcode = (decrypted_packet[1] >> 4) & 0x0F

# Se o opcode for 9 (0b1001), é o Colete a conf irmar que ouviu o Dashboard print(f"[ACK] Colete {vest_id} confirmou a rece ção da mensagem.")

return {
"tipo": "ACK",
"vest_id": vest_id,
"status": "RECEBIDO"
}

return None # Se o pacote chegou estragado ou com um ta manho inválido, ignora

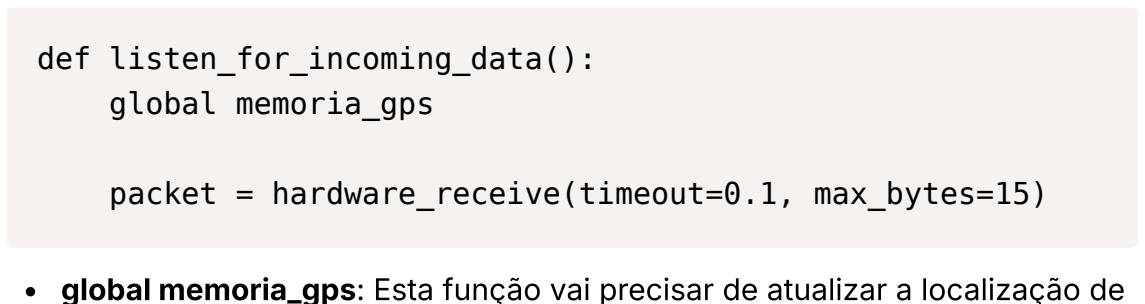
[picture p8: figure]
def listen_for_incoming_data(): global memoria_gps; packet = hardware_receive(timeout=0.1, max_bytes=15)

global memoria_gps: Esta função vai precisar de atualizar a localização de todos os coletes no mapa, o que esta linha faz é pedir autorização para poder alterar.

hardware_receive(...): Fica à escuta na porta UART (ou LoRa) durante o tempo definido. Se chegar alguma coisa (máximo de 15 bytes), guarda

no packet.

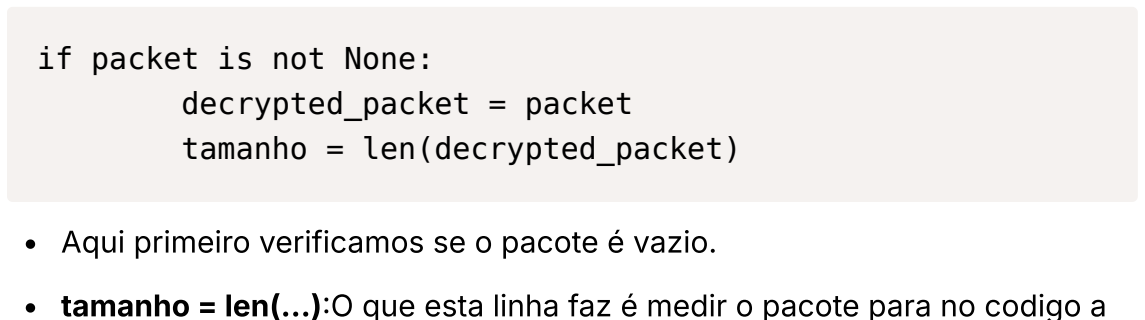
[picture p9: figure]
if packet is not None: decrypted_packet = packet tamanho = len(decrypted_packet)

Aqui primeiro verificamos se o pacote é vazio.

tamanho = len(...):O que esta linha faz é medir o pacote para no codigo a baixo decidir para que if a mensagem vai ser enviada.

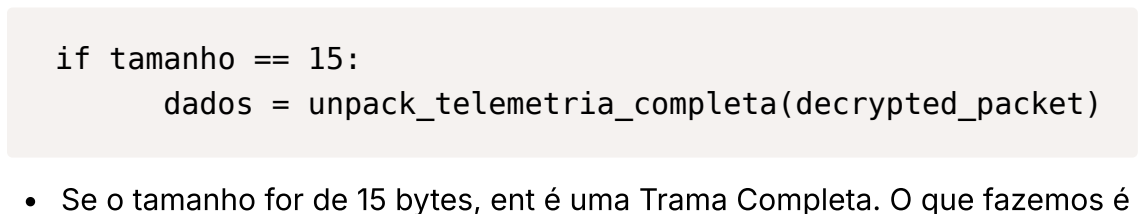
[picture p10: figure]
if tamanho == 15: dados = unpack_telemetria_completa(decrypted_packet)

Se o tamanho for de 15 bytes, ent é uma Trama Completa. O que fazemos é chamar a função unpack_telemetria_completa(…) para desempacotar.

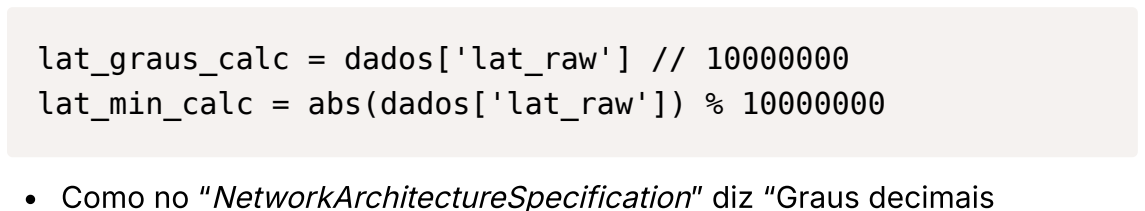
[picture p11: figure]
lat_graus_calc = dados['lat_raw'] // 10000000 lat_min_calc = abs(dados['lat_raw']) % 10000000

Como no “NetworkArchitectureSpecification” diz “Graus decimais multiplicados por 10^7” então aqui vamos ter que fazer o oposto. Primeiro
fazemos a divisão inteira por 10^7 | (// 10000000), aqui extraimos
apenas os graus (ex: 38) depois fazermos o resto da divisão | (%
10000000) de onde tiramos as casas decimais(ex: 7500000).

Isto é guardado na memoria_gps[vest_id].

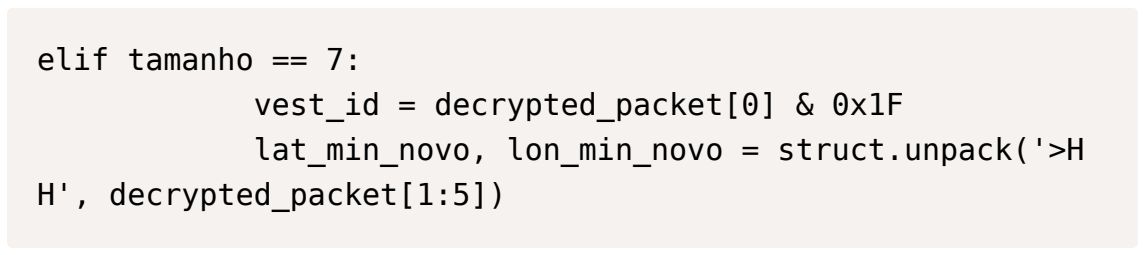
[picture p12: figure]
elif tamanho == 7: vest_id = decrypted_packet[0] & 0x1F lat_min_novo, lon_min_novo = struct.unpack('>H H', decrypted_packet[1:5])

Como o colete só envia a Trama Completa de 10 em 10 minutos. Nos intervalos, é enviada apenas a Trama de Posição(delta) que tem o tamanho de 7 bytes. Esta trama não contém os graus só tem os decimais do GPS, porque os graus não estão constantemente a mudar logo não ha necessidade de estar sempre a enviá-los.

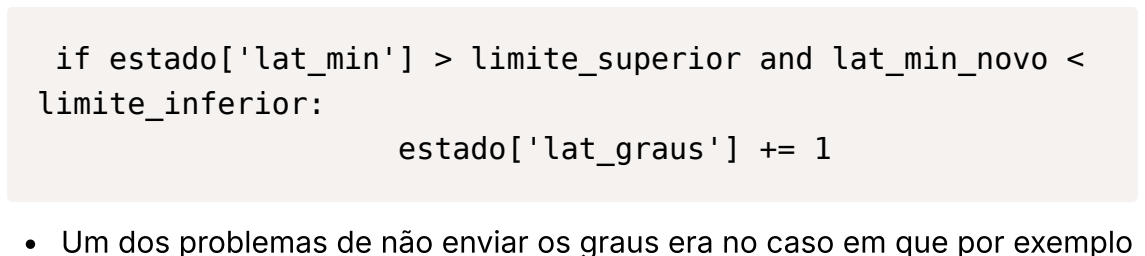
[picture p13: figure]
limite_inferior:; estado['lat_graus'] += 1

if estado['lat_min'] > limite_superior and lat_min_novo <

Um dos problemas de não enviar os graus era no caso em que por exemplo o bombeiro estava na coordenada 38.9999999 e dava um passo para a frente para a coordenada 39.0000001 . Para resolver isso foi implementado o seguinte:

Se a memória antiga (estado['lat_min']) estava perto do valor máximo(ex: 9.900.000) e a nova leitura (lat_min_novo) está perto do mínimo (ex: 100.000), então isso significa que o bombeiro mudou o grau. Então no código, somamos +1 Grau à memória.

Para o inverso, a lógica é a “mesma” (-= 1) ( caso em que ele andar para trás).

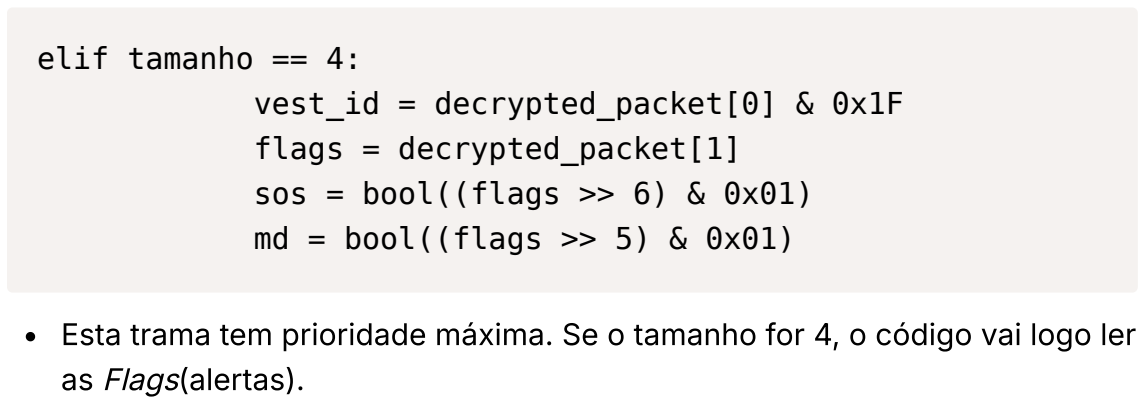
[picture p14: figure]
elif tamanho == 4: vest_id = decrypted_packet[0] & 0x1F flags = decrypted_packet[1] sos = bool((flags >> 6) & 0x01) md = bool((flags >> 5) & 0x01); as Flags(alertas).

Esta trama tem prioridade máxima. Se o tamanho for 4, o código vai logo ler

O operador >> 6 é usado para ler o bit do (SOS) e o operador >> 5 é usado para ler o bit de Man Down (se o bombeiro caiu no chão).

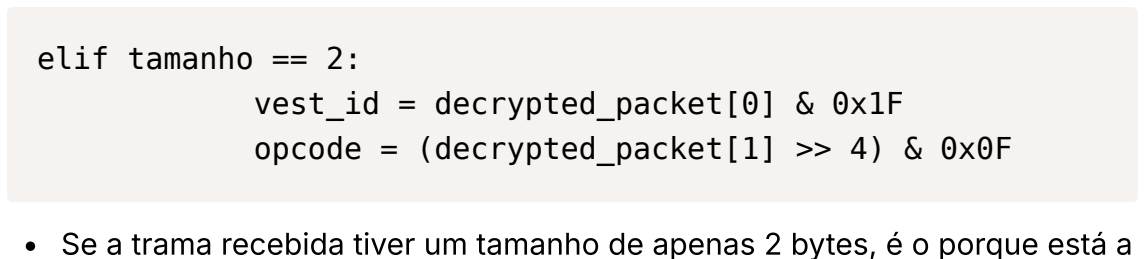
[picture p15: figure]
elif tamanho == 2: vest_id = decrypted_packet[0] & 0x1F

opcode = (decrypted_packet[1] >> 4) & 0x0F

Se a trama recebida tiver um tamanho de apenas 2 bytes, é o porque está a haver comunicação. Verifica qual é o comando (se o opcode é o 9,(1001) ) e avisa que uma mensagem foi recebida com sucesso pela rede.

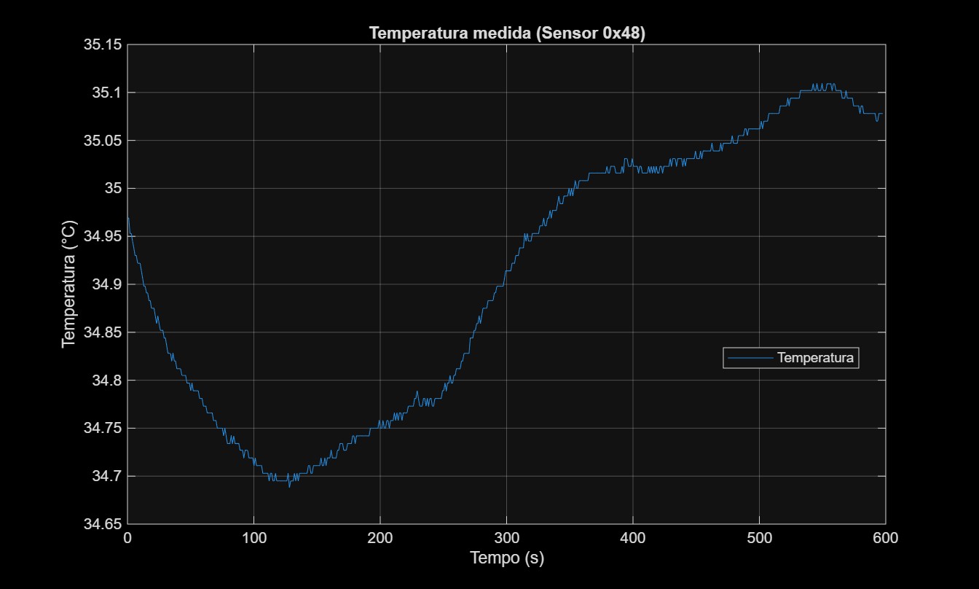
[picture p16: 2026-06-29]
Documentation/V&P Team/Graphics/Graficos TMP117/Grafico_1_Sensor_Peito_10_Minutos_CF_V2.jpg

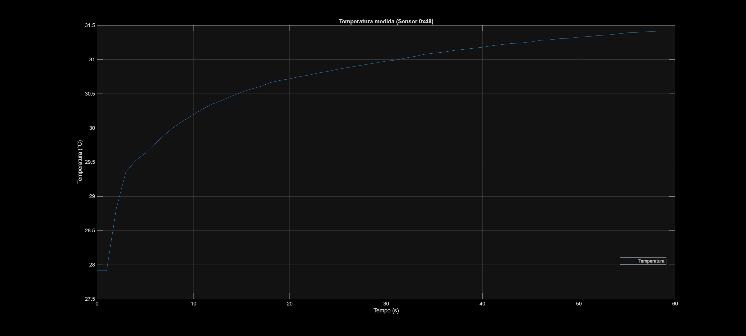
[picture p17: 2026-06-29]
Documentation/V&P Team/Graphics/Graficos TMP117/Grafico_1_Sensor_Pulso_1_Minuto_PB.jpg

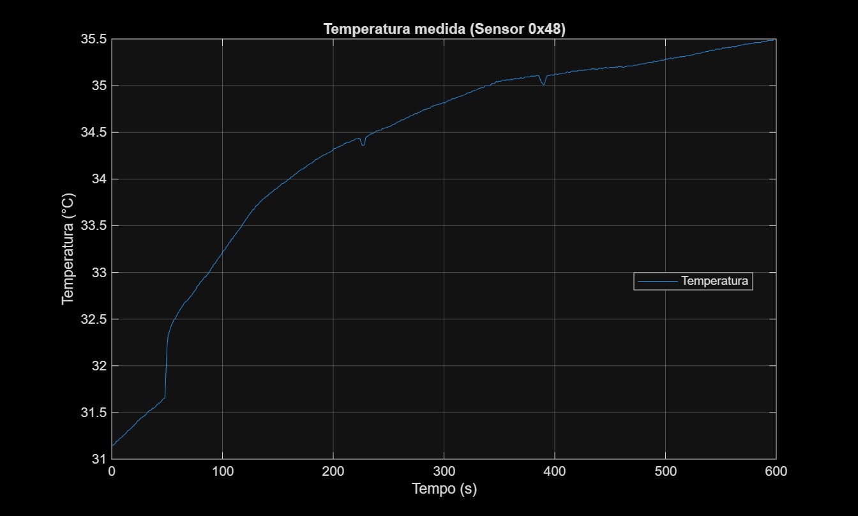
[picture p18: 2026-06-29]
Documentation/V&P Team/Graphics/Graficos TMP117/Grafico_1_Sensor_Peito_10_Minutos_CF.jpg

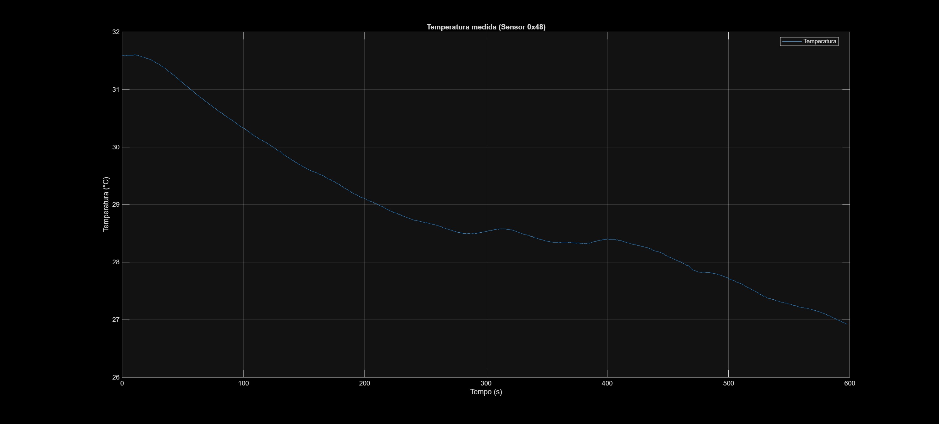
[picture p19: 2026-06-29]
Documentation/V&P Team/Graphics/Graficos TMP117/Grafico_1_Sensor_Ponta_Dedo_10_Minuto_CF_OutroSensor.jpg

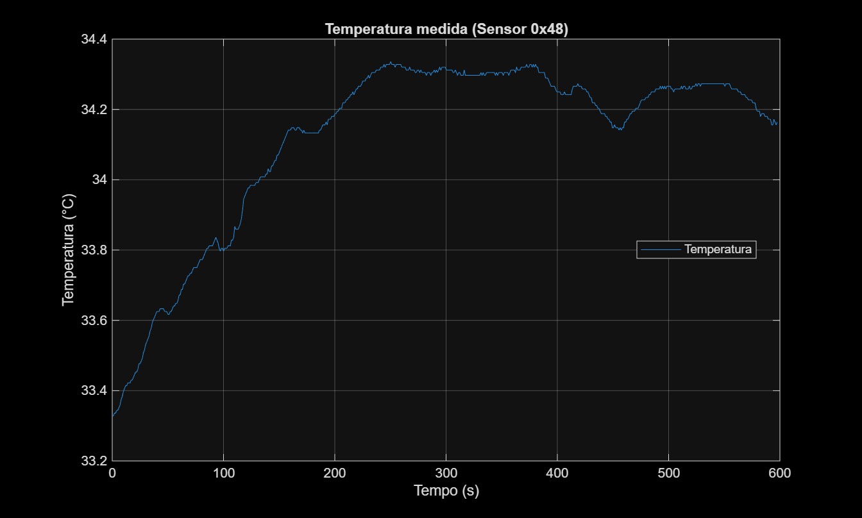
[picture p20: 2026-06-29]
Documentation/V&P Team/Graphics/Graficos TMP117/Grafico_1_Sensor_Pulso_10_Minutos_CF.jpg

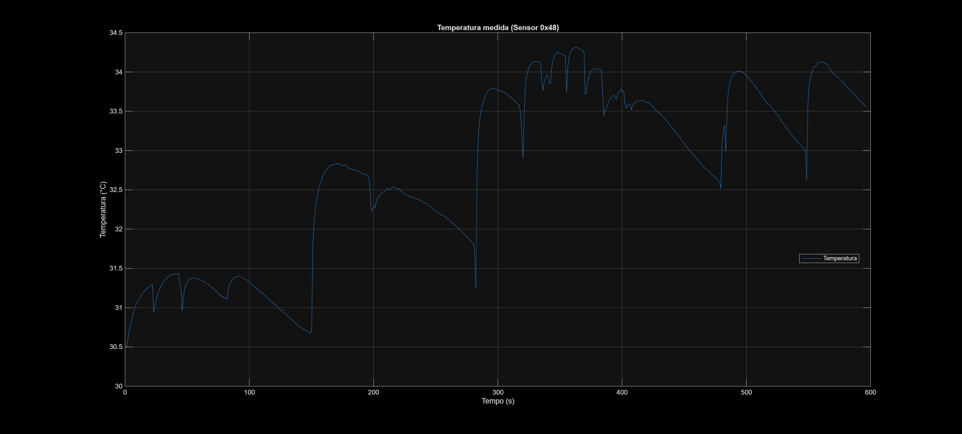
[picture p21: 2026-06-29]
Documentation/V&P Team/Graphics/Graficos TMP117/Grafico_1_Sensor_Varios_Dedos_PB.jpg

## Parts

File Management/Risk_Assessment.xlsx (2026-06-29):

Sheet: Risk Assessment Up To Date
Risks | Cause | PxI | P | I | Impact | Mitigation
 |  |  |  |  |  |  | Up to Date Page: |  | Riscos 10_04
Delay in Delivery of Critical Components | Delays in the supply of modules | 10 | 2 | 5 | Impossibility of assembling the final prototypes in time for validations (M16.5). | Validate alternative vendors and modules
PCB Manufacturing Defect | Factory error in the production of the board or errors in the tracks due to lack of layers not initially foreseen. | 10 | 2 | 5 | Mounted hardware does not work; Critical delay waiting for a new card. | Design PCBs early by complying with standards; Quickly test connectivity on arrival. |  | Risk Matrix 5x5 (PxI): |  |  |  | Impact
Battery Thermal Failure | The heat from the fire penetrates the vest, activating the battery's internal protection or degrading it. | 10 | 2 | 5 | The system suddenly switches off during the mission; Loss of autonomy. | Integration of a custom Power Module to ensure electrical stability. |  |  |  |  |  | 1 (Pouco) | 2 | 3 | 4 | 5 (Grande)
LoRa Band Jamming/Interference | Saturation of the free band (ISM 868MHz) by other devices in the area or Intentional/accidental jamming at the fire site. | 10 | 2 | 5 | Total loss of communication with the tablet; inability to report Man Down and other alerts. | Development of a custom MAC protocol using TDMA and state machine to control Sub-Channel Hopping. |  |  |  | Probability | 1 (Raro) | 1 | 2 | 3 | 4 | 5
Motion Artifacts | PPG sensor technology has physical difficulty reading through sweat/intense motion, regardless of code quality. | 8 | 2 | 4 | False alarms of cardiac arrest or lack of data during active combat. | Implementation of continuous reading and intelligent algorithms to reject false positives. |  |  |  |  | 2 | 2 | 4 | 6 | 8 | 10
Vest Material | Uncomfortable material, with low breathability and that does not protect the modules much from external temperature. | 6 | 2 | 3 | Increased operational fatigue; Wrong biometric readings; Overheating of the electronic modules; | Manufacture of the vest with breathable fabrics (cotton); Possibility of adjusting to the body with velcro. |  |  |  |  | 3 | 3 | 6 | 9 | 12 | 15
Test Environment Unavailability | Lack of access to the Fire Department or facilities to conduct the actual field tests. | 4 | 2 | 2 | The product is validated only in the laboratory and may fail in a real scenario. | Schedule tests with partners in advance. |  |  |  |  | 4 | 4 | 8 | 12 | 16 | 20
UWB Multipath Failure | Reflections of the UWB signal on metal structures/electricity poles create false distance readings. | 4 | 2 | 2 | High positioning error in case of GNSS failure | Discard impossible sudden variations and try to predict possible positions. |  |  |  |  | 5 (Muito Certo) | 5 | 10 | 15 | 20 | 25
Microcontroller Overload | The combined load of Encryption (AES-128), Sensor Fusion, and LoRa Management exceeds the clock cycles available on the ESP32. | 3 | 1 | 3 | High latency in sending alerts; Slow system or Watchdog timeout crash. | Code optimization (use the 2 cores of the ESP32); Reduce the sampling frequency if necessary.

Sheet: Riscos 06_12
Riscos | Causa | PxI | P | I | Impacto | Mitigação
Leituras Erradas em Movimento (Motion Artifacts) | A tecnologia do sensor PPG tem dificuldade física em ler através do suor/movimento intenso, independentemente da qualidade do código. | 16 | 4 | 4 | Falsos alarmes de paragem cardíaca ou falta de dados durante combate ativo. | Algoritmo que filtrr ofsets no PPG; Usar sensores como um acelerómetro auxiliar para determinar o sinal; Algoritmo de validação de sinal. | Matriz de Risco 5x5 (PxI):
Falha Térmica da Bateria | O calor do incêndio penetra no colete, ativando a proteção interna da bateria ou degradando-a. | 15 | 3 | 5 | O sistema desliga-se subitamente durante a missão; Perda de autonomia. | Utilizar isolamento térmico no invólucro da bateria; Monitorização ativa da temperatura interna pelo BMS. |  |  |  | Impacto
Bloqueio/Interferência na Banda LoRa | Saturação da banda livre (ISM 868MHz) por outros dispositivos na área ou Jamming intencional/acidental no local do incêndio. | 12 | 3 | 4 | Perda total de comunicação com o tablet; incapacidade de reportar Man Down e outros alertas. | Ter buffer de dados local para reenvio posterior; Avisar quando algum colete não transmitiu dados. |  |  |  | 1 (Pouco) | 2 | 3 | 4 | 5 (Grande)
Atraso na Entrega de Componentes Críticos | Atrasos no fornecimento de módulos | 10 | 2 | 5 | Impossibilidade de montar os protótipos finais a tempo das validações (M16.5). | Validar fornecedores e módulos alternativos |  | Probabilidade | 1 (Raro) | 1 | 2 | 3 | 4 | 5
Defeito de Fabrico do PCB | Erro da fábrica na produção da placa ou erros nas pistas por falta de camadas inicialmente não previstas. | 10 | 2 | 5 | O hardware montado não funciona; atraso crítico à espera de uma nova placa. | Fazer o design dos PCBs cedo cumprindo as normas; Testar rapidamente a conectividade à chegada. |  |  | 2 | 2 | 4 | 6 | 8 | 10
Indisponibilidade de Ambiente de Teste | Falta de acesso aos Bombeiros ou a instalações para realizar os testes de campo reais. | 6 | 2 | 3 | O produto é validado apenas em laboratório e pode falhar em cenário real. | Agendar testes com os parceiros com tempo de antecedência. |  |  | 3 | 3 | 6 | 9 | 12 | 15
Material do Colete | Material desconfortável, com baixa respirabilidade e que não protege muito os módulos da temperatura externa. | 6 | 2 | 3 | Aumento da fadiga do operacional; Leituras biométricas errada; Sobreaquecimento dos módulos eletrónicos; | Fabricação do colete com tecidos respiráveis (algodão); Possibilidade de ajustar ao corpo com velcro. |  |  | 4 | 4 | 8 | 12 | 16 | 20
Falha de Multicaminho (Multipath) UWB | Reflexões do sinal UWB em estruturas metálicas/postes de eletrecidade criam leituras de distância falsas. | 4 | 2 | 2 | Erro de posicionamento elevado, caso haja falha no GNSS | Descartar variações súbitas impossíveis e tentar prever posições possíveis. |  |  | 5 (Muito Certo) | 5 | 10 | 15 | 20 | 25
Sobrecarga do Microcontrolador | A carga combinada de Criptografia (AES-128), Fusão de Sensores e Gestão LoRa excede os ciclos de clock disponíveis no ESP32. | 3 | 1 | 3 | Latência elevada no envio de alertas; Sistema lento ou crash por timeout do Watchdog. | Otimização de código (utilizar os 2 cores do ESP32); Reduzir a frequência de amostragem se necessário.

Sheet: Riscos 10_04
Riscos | Causa | PxI | P | I | Impacto | Mitigação
Atraso na Entrega de Componentes Críticos | Atrasos no fornecimento de módulos | 10 | 2 | 5 | Impossibilidade de montar os protótipos finais a tempo das validações (M16.5). | Validar fornecedores e módulos alternativos | Matriz de Risco 5x5 (PxI):
Defeito de Fabrico do PCB | Erro da fábrica na produção da placa ou erros nas pistas por falta de camadas inicialmente não previstas. | 10 | 2 | 5 | O hardware montado não funciona; atraso crítico à espera de uma nova placa. | Fazer o design dos PCBs cedo cumprindo as normas; Testar rapidamente a conectividade à chegada. |  |  |  | Impacto
Falha Térmica da Bateria | O calor do incêndio penetra no colete, ativando a proteção interna da bateria ou degradando-a. | 10 | 2 | 5 | O sistema desliga-se subitamente durante a missão; Perda de autonomia. | Integração de um Módulo de Energia personalizado para gantir estabilidade elétrica. |  |  |  | 1 (Pouco) | 2 | 3 | 4 | 5 (Grande)
Bloqueio/Interferência na Banda LoRa | Saturação da banda livre (ISM 868MHz) por outros dispositivos na área ou Jamming intencional/acidental no local do incêndio. | 10 | 2 | 5 | Perda total de comunicação com o tablet; incapacidade de reportar Man Down e outros alertas. | Desenvolvimento de um protocolo MAC personalizado com recurso a TDMA e máquina de estados para controlar Saltar de Sub Canal. |  | Probabilidade | 1 (Raro) | 1 | 2 | 3 | 4 | 5
Leituras Erradas em Movimento (Motion Artifacts) | A tecnologia do sensor PPG tem dificuldade física em ler através do suor/movimento intenso, independentemente da qualidade do código. | 8 | 2 | 4 | Falsos alarmes de paragem cardíaca ou falta de dados durante combate ativo. | Implementação de leitura contínua e algoritmos inteligentes para rejeitar falsos positivos. |  |  | 2 | 2 | 4 | 6 | 8 | 10
Material do Colete | Material desconfortável, com baixa respirabilidade e que não protege muito os módulos da temperatura externa. | 6 | 2 | 3 | Aumento da fadiga do operacional; Leituras biométricas errada; Sobreaquecimento dos módulos eletrónicos; | Fabricação do colete com tecidos respiráveis (algodão); Possibilidade de ajustar ao corpo com velcro. |  |  | 3 | 3 | 6 | 9 | 12 | 15
Indisponibilidade de Ambiente de Teste | Falta de acesso aos Bombeiros ou a instalações para realizar os testes de campo reais. | 4 | 2 | 2 | O produto é validado apenas em laboratório e pode falhar em cenário real. | Agendar testes com os parceiros com tempo de antecedência. |  |  | 4 | 4 | 8 | 12 | 16 | 20
Falha de Multicaminho (Multipath) UWB | Reflexões do sinal UWB em estruturas metálicas/postes de eletrecidade criam leituras de distância falsas. | 4 | 2 | 2 | Erro de posicionamento elevado, caso haja falha no GNSS | Descartar variações súbitas impossíveis e tentar prever posições possíveis. |  |  | 5 (Muito Certo) | 5 | 10 | 15 | 20 | 25
Sobrecarga do Microcontrolador | A carga combinada de Criptografia (AES-128), Fusão de Sensores e Gestão LoRa excede os ciclos de clock disponíveis no ESP32. | 3 | 1 | 3 | Latência elevada no envio de alertas; Sistema lento ou crash por timeout do Watchdog. | Otimização de código (utilizar os 2 cores do ESP32); Reduzir a frequência de amostragem se necessário.

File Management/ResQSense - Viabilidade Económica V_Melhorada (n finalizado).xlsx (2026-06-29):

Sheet: 1. Premissas
1. Premissas
Variáveis globais.
# | Variável | Valor | Observações
1 | Taxa IVA | 23%
2 | TSU Empresa | 23.75%
3 | Preço Venda Base - Pacote | 7500.00 €
4 | Eficiência Ano 1 (Horas por Pacote) | 120
5 | Eficiência Ano 3 (Horas por Pacote) | 40
6 | Margem | 40%
7 | Custo da eletrónica ao fim de 3anos | -10%

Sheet: 2. Investimento Inicial
2. Investimento Inicial
Lista de compras inicial e ativos fixos.
# | Investimento | Valor Orçamentado | Taxa IVA | Total
1 | Equipamento Informático | 3500.00 € | 23% | 4305.00 €
2 | Software | 1500.00 € | 0% | 1500.00 €
3 | Impressora 3D | 1500.00 € | 23% | 1845.00 €
4 | Ferramentas | 600.00 € | 23% | 738.00 €
5 | Osciloscópio | 1200.00 € | 23% | 1476.00 €
6 | Estação de Solda | 450.00 € | 23% | 553.50 €
7 | Certificações | 5000.00 € | 0% | 5000.00 €
8 | Fios e Cobre |  | 0% | 0.00 €
9 | Material Para 1 Pacote |  | 0% | 0.00 €
TOTAL: |  | 13750.00 € |  | 15417.50 €

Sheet: 3. BOM & Produção
3. Bill Of Materials & Produção
Cálculo do custo variável por pacote vendido.
Custo Atual
(x1) Montioring Vest |  |  |  |  | (x1) Dashboard Tablet
Notas | Componente | Descrição | Qtd. | Preço | Notas | Componente | Descrição | Qtd. | Preço
Comprar só o chip e fazer a placa | ESP32-S3 Wroom 1 N8R8 | MCU | 1 | 11.90 € |  | Raspberry PI3 Model B+ | MCU | 1 | 39.86 €
 | TMP117 | Temperatura | 3 | 9.86 € | Poderia ser outo touchscreen | SC0880 | Touchscreen | 1 | 66.90 €
Comprar só o sensor smd PPG | SEN0344 | PPG | 1 | 13.58 € |  | BNO085 | IMU 9 eixos | 1 | 24.95 €
 | MPU6050 | IMU | 1 | 8.70 € |  | PC81.07.0100A.DB | Antena LoRa | 1 | 6.67 €
 | DFR1103 | GNSS | 1 | 22.11 € |  | RECE.20279.001E.01 | Conector Antena | 1 | 1.05 €
 | DWM3000TR13 | UWB | 1 | 23.11 € |  | Adafruit RFM95W | LoRa Transciever | 1 | 19.95 €
 | PC81.07.0100A.DB | Antena LoRa | 1 | 6.67 € |  | Speaker 8ohm | - | 1 | 8.50 €
 | RECE.20279.001E.01 | Conector Antena | 1 | 1.05 € |  | BC547C | BJT NPN | 1 | 0.05 €
 | Adafruit RFM95W | LoRa Transciever | 1 | 19.95 € |  | BC557C | BJT PNP | 1 | 0.05 €
 | FSR406 | "SOS Button" | 1 | 12.40 € |  | Bobine | Bobine | 1 | 1.50 €
 | TLV75733PDBVR | LDO Regulator | 1 | 0.33 € |  | LiFePo4 7,4v 10Ah | Bateria | 1 | 35.00 €
 | TPS2113APWR | Power Mux | 1 | 2.64 € |  | BMS | p/ carregar bateria | 1 | 10.00 €
 | MF52A2103J3470 | Thermístor NTC | 1 | 0.32 € |  | Filamentos | p/ Impressão 3D | 1 | 15.00 €
Comprar outro para uma LiFePo4 | Adafruit MAX17048 | Fuel Gauge | 1 | 5.95 € | Valor Aproximado | Extra Resistors | - | 1 | 5.00 €
Valor Aprox | LiFePo4 3,7v 1Ah | Bateria Principal | 1 | 10.00 € | Valor Aproximado | Extra Capacitors | - | 1 | 8.00 €
Outra bateria sem ser de lítio | 2CR5 | Bateria Backup | 1 | 6.40 € | 1 design (5 placas) = 5,00 | PCB Manufacturing | - | 1 | 5.00 €
 | VN2222 | MOSFETs | 2 | 0.68 € |  | Portes de Envio | - | 1 | 20.00 €
Valor Aproximado | Extra Resistors | - | 1 | 5.00 € | TOTAL: |  |  |  | 267.48 €
Valor Aproximado | Extra Capacitors | - | 1 | 8.00 €
1 design (5 placas) = 5,00 | PCB Manufacturing | - | 5 | 5.00 €
 | Portes de Envio | - | 1 | 20.00 €
 | Tecido | - | 1 | 50.00 €
TOTAL: |  |  |  | 284.05 €
1 | Total Eletrónica (5v + 1t): | 1687.73 €
2 | Ao fim de 3 anos | 1518.96 €
3 | Packaging | 150.00 €
4 | Logística & Transporte | 50.00 €
5 | Custo de Mão de Obra

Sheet: 4. Quadro Pessoal
4. Quadro de Pessoal
Evolução da equipa e custos fixos de ordenados.
Quadro Pessoal |  | Ano I | Ano II | Ano III | Ano IV | Ano V | Ano VI | Ano VII | Ano VIII | Ano IX | Ano X
CTO |  | 1 | 1 | 1 | 1 | 1 | 1 | 1 | 1 | 1 | 1
Team Leaders |  | 2 | 2 | 2 | 3 | 3 | 3 | 3 | 3 | 3 | 3
Engenheiros |  | - | - | 2 | 6 | 6 | 9 | 9 | 9 | 9 | 9
Técnicos de Montagem |  | - | 1 | 2 | 3 | 3 | 3 | 3 | 3 | 3 | 3
Apoio Ao Cliente |  | - | - | 1 | 1 | 1 | 3 | 3 | 3 | 3 | 3
Marketing |  | - | - | 1 | 1 | 1 | 3 | 3 | 3 | 3 | 3
Total Nº Colaboradores: |  | 3 | 4 | 9 | 15 | 15 | 22 | 22 | 22 | 22 | 22
Remuneração Por Categoria (/mês)
Taxa crescimento dos salários: | 2%
CTO |  | 2000.00 € | 2000.00 € | 2040.00 € | 2080.80 € | 2122.42 € | 2164.86 € | 2208.16 € | 2252.32 € | 2297.37 € | 2343.32 €
Team Leaders |  | 2000.00 € | 2000.00 € | 2040.00 € | 2080.80 € | 2122.42 € | 2164.86 € | 2208.16 € | 2252.32 € | 2297.37 € | 2343.32 €
Engenheiros |  | 0.00 € | 0.00 € | 1800.00 € | 1836.00 € | 1872.72 € | 1910.17 € | 1948.38 € | 1987.35 € | 2027.09 € | 2067.63 €
Técnicos de Montagem |  | 0.00 € | 1000.00 € | 1020.00 € | 1040.40 € | 1061.21 € | 1082.43 € | 1104.08 € | 1126.16 € | 1148.69 € | 1171.66 €
Apoio Ao Cliente |  | 0.00 € | 0.00 € | 1200.00 € | 1224.00 € | 1248.48 € | 1273.45 € | 1298.92 € | 1324.90 € | 1351.39 € | 1378.42 €
Marketing |  | 0.00 € | 0.00 € | 1550.00 € | 1581.00 € | 1612.62 € | 1644.87 € | 1677.77 € | 1711.33 € | 1745.55 € | 1780.46 €
Total de Vencimentos: |  | 6000.00 € | 7000.00 € | 14510.00 € | 25265.40 € | 25770.71 € | 37853.29 € | 38610.36 € | 39382.56 € | 40170.21 € | 40973.62 €

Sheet: 5. Despesas Fixas
5. Despesas Fixas
Custos fixos que garantem a operação da empresa.
 |  | Fornecimentos e Serviços de Terceiros (p/ano)
 | Ano I | Ano II | Ano III | Ano IV | Ano V | Ano VI | Ano VII | Ano VIII | Ano IX | Ano X
Energia e Fluídos
Eletricidade | 2400.00 € | 2400.00 € | 2400.00 € | 2400.00 € | 2400.00 € | 2400.00 € | 2400.00 € | 2400.00 € | 2400.00 € | 2400.00 €
Água | 600.00 € | 600.00 € | 600.00 € | 600.00 € | 600.00 € | 600.00 € | 600.00 € | 600.00 € | 600.00 € | 600.00 €
Serviços Diversos
Comunicações (Internet, Hosting, Tel.) | 1200.00 € | 1200.00 € | 1200.00 € | 1200.00 € | 1200.00 € | 1200.00 € | 1200.00 € | 1200.00 € | 1200.00 € | 1200.00 €
Seguros | 1500.00 € | 1500.00 € | 1500.00 € | 1500.00 € | 1500.00 € | 1500.00 € | 1500.00 € | 1500.00 € | 1500.00 € | 1500.00 €
Higiéne e Segurança no Trabalho | 150.00 € | 150.00 € | 150.00 € | 150.00 € | 150.00 € | 150.00 € | 150.00 € | 150.00 € | 150.00 € | 150.00 €
Escritório (Renda) | 12000.00 € | 12000.00 € | 12000.00 € | 24000.00 € | 24000.00 € | 42000.00 € | 42000.00 € | 42000.00 € | 42000.00 € | 42000.00 €
Materiais
Material de Escritório | 200.00 € | 200.00 € | 200.00 € | 200.00 € | 200.00 € | 200.00 € | 200.00 € | 200.00 € | 200.00 € | 200.00 €
Deslocações (km*combustivel+portagens)
Deslocações | 7500.00 € | 8625.00 € | 9918.75 € | 11406.56 € | 13117.55 € | 15085.18 € | 17347.96 € | 19950.15 € | 22942.67 € | 26384.07 €
Serviços Especializados
Contabilidade | 3600.00 € | 3600.00 € | 3600.00 € | 3600.00 € | 3600.00 € | 3600.00 € | 3600.00 € | 3600.00 € | 3600.00 € | 3600.00 €
Manutenção | 120.00 € | 120.00 € | 120.00 € | 120.00 € | 120.00 € | 120.00 € | 120.00 € | 120.00 € | 120.00 € | 120.00 €
Servidores | 1000.00 € | 1000.00 € | 1000.00 € | 1000.00 € | 1000.00 € | 1000.00 € | 1000.00 € | 1000.00 € | 1000.00 € | 1000.00 €
Total: | 30270.00 € | 31395.00 € | 32688.75 € | 46176.56 € | 47887.55 € | 67855.18 € | 70117.96 € | 72720.15 € | 75712.67 € | 79154.07 €

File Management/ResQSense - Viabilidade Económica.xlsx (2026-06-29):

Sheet: Versão 1
Custos de Fabricação ResQSense
(x1) Montioring Vest |  |  |  |  |  | (x1) Dashboard Tablet
Notas | Componente | Descrição | Qtd. | Preço |  | Notas | Componente | Descrição | Qtd. | Preço
Comprar só o chip e fazer a placa | ESP32-S3 Wroom 1 N8R8 | MCU | 1 | 11.90 € |  |  | Raspberry PI3 Model B+ | MCU | 1 | 39.86 €
 | TMP117 | Temperatura | 3 | 9.86 € |  | Poderia ser outo touchscreen | SC0880 | Touchscreen | 1 | 66.90 €
Comprar só o sensor smd PPG | SEN0344 | PPG | 1 | 13.58 € |  |  | BNO085 | IMU 9 eixos | 1 | 24.95 €
 | MPU6050 | IMU | 1 | 8.70 € |  |  | PC81.07.0100A.DB | Antena LoRa | 1 | 6.67 €
 | DFR1103 | GNSS | 1 | 22.11 € |  |  | RECE.20279.001E.01 | Conector Antena | 1 | 1.05 €
 | DWM3000TR13 | UWB | 1 | 23.11 € |  |  | Adafruit RFM95W | LoRa Transciever | 1 | 19.95 €
 | PC81.07.0100A.DB | Antena LoRa | 1 | 6.67 € |  |  | Speaker 8ohm | - | 1 | 8.50 €
 | RECE.20279.001E.01 | Conector Antena | 1 | 1.05 € |  |  | BC547C | BJT NPN | 1 | 0.05 €
 | Adafruit RFM95W | LoRa Transciever | 1 | 19.95 € |  |  | BC557C | BJT PNP | 1 | 0.05 €
 | FSR406 | "SOS Button" | 1 | 12.40 € |  |  | Bobine | Bobine | 1 | 1.50 €
 | TLV75733PDBVR | LDO Regulator | 1 | 0.33 € |  |  | LiFePo4 7,4v 10Ah | Bateria | 1 | 35.00 €
 | TPS2113APWR | Power Mux | 1 | 2.64 € |  |  | BMS | p/ carregar bateria | 1 | 10.00 €
 | MF52A2103J3470 | Thermístor NTC | 1 | 0.32 € |  |  | Filamentos | p/ Impressão 3D | 1 | 15.00 €
Comprar outro para uma LiFePo4 | Adafruit MAX17048 | Fuel Gauge | 1 | 5.95 € |  | Valor Aproximado | Extra Resistors | - | 1 | 5.00 €
Valor Aprox | LiFePo4 3,7v 1Ah | Bateria Principal | 1 | 10.00 € |  | Valor Aproximado | Extra Capacitors | - | 1 | 8.00 €
Outra bateria sem ser de lítio | 2CR5 | Bateria Backup | 1 | 6.40 € |  | 1 design (5 placas) = 5,00 | PCB Manufacturing | - | 1 | 5.00 €
 | VN2222 | MOSFETs | 2 | 0.68 € |  |  | Portes de Envio | - | 1 | 20.00 €
Valor Aproximado | Extra Resistors | - | 1 | 5.00 € |  | TOTAL: |  |  |  | 267.48 €
Valor Aproximado | Extra Capacitors | - | 1 | 8.00 €
1 design (5 placas) = 5,00 | PCB Manufacturing | - | 5 | 5.00 €
 | Portes de Envio | - | 1 | 20.00 €
 | Tecido | - | 1 | 50.00 €
TOTAL: |  |  |  | 284.05 €
Kit de Intervenção: 5 Monitoring Vest + 1 Dashboard Tablet
Custo Total de 1 Kit: | 1687.73 €
c/IVA | 2075.91 €
Outros Custos
Nome | Periodicidade | Qtd. | Valor
Infraestrutura
Agua | p/ano | 1 | 600.00 €
Luz | p/ano | 1 | 2400.00 €
Gás | p/ano | 1 | 400.00 €
Escritório (Renda) | p/ano | 1 | 15000.00 €
Internet & Hosting | p/ano | 1 | 1200.00 €
Impressora 3D | p/ano | 1 | 3500.00 €
Pessoal
Engenheiros | p/ano | 8 | 51975.00 €
Team Leaders | p/ano | 3 | 71775.00 €
Marketing | p/ano | 1 | 76725.00 €
CTO | p/ano | 1 | 105187.50 €
Outros
Imprevistos (10%) | p/ano | 1 | 70000.00 €
Manutenção | p/ano | 1 | 10000.00 €
TOTAL: |  |  | 916137.50 €
Modelo de Negócio e Estrutura de Receitas
Modelo de Negócio
A Wearion adota um modelo de negócio B2B Hibrido: A venda inicial do Hardware assegura uma receita imediata (CAPEX) e posteriormente o modelo HaaS garante umfluxo de receita recorrente (OPEX).
ResQSense (CAPEX) | Para o ResQSense (Kit), a Wearion establece parcerias com fabricantes de EPIs nacionalmente (e a nível europeu) conhecidos. Ao atribuir uma comissão de 15% sobre a venda, a Wearion garante uma penetração de mercado acelerada e preços competitivos, eliminando a necessidade de um elevado CAC (Customer Acquisition Cost).
 | Lucro ResQSense
 | Item | Valor |  |  |  | Tabela de Comparação de Custos (por Bombeiro)
 | Custo de Produção do Kit (inc. IVA) | 2075.91 € |  |  |  | Equipamento | Custo Estatístico (s/ IVA) | Custo Estatístico (c/ IVA)
 | Preço de Venda (B2B) | 9500.00 € |  |  |  | Fato Nomex Completo | 927.00 € | 1140.21 €
 | Comissão p/ Parceiros (15%) | -1425.00 € |  |  |  | Câmara Térmica | 1057.00 € | 1300.11 €
 | Receita Líquida: | 8075.00 € |  |  |  | Botas Profissionais | 150.00 € | 184.50 €
 | Lucro Bruto p/ Kit: | 5999.09 € |  |  |  | Kit ResQSense (Custo Médio) | 1287.00 € | 1583.01 €
 | Margem de Lucro: | 63.15%
 |  |  |  |  |  | Nota: O Custo Médio do Kit ResQSense é calculado fazendo uma média por cada dispositivo
HaaS (OPEX) | Para o HaaS, a Wearion pensa em fronecer os seguintes serviços: Basic Data Cloud; Training Analysis; Preventive Maintenance; Command App. Para ajudar a reter o cliente, o pacote Basic Data Cloud era oferecido no primeiro ano após a compra.
 | Serviço | Descrição | Preço de Venda | Custo | Margem Bruta
 | Basic Data Cloud | Sincronização em tempo real e armazenamento de dados de alertas na Cloud | 1200.00 € | 120.00 € | 90%
 | Training Analysis | Armazenamento dos dados completos da missão e relatórios de performance pós-missão. | 2500.00 € | 250.00 € | 90%
 | Preventive Maintenance | Verificação de integridade dos sensores/baterias e a substituição proativa. | 1500.00 € | 450.00 € | 70%
 | Command App | Licenciamento para monitorização global de múltiplas equipas. | 5000.00 € | 500.00 € | 90%
Resultado Anual (Base 100 kits):
ResQSense: | 599909.21 €
HaaS (média): | 200000.00 €
Cumulative Cash Flow
Ano | Kits Vendidos | Lucro Hardware | Lucro HaaS | Custos | Fluxo de Caixa Anual | Fluxo Acumulado
0 | 0 | 0.00 € | 0.00 € | -50000.00 € | -50000.00 € | -50000.00 €
1 | 15 | 89986.38 € | 12000.00 € | -916137.50 € | -814151.12 € | -864151.12 €
2 | 25 | 149977.30 € | 50000.00 € | -916137.50 € | -716160.20 € | -1580311.32 €
3 | 50 | 299954.60 € | 120000.00 € | -916137.50 € | -496182.90 € | -2076494.21 €
4 | 100 | 599909.21 € | 260000.00 € | -916137.50 € | -56228.29 € | -2132722.50 €
5 | 175 | 1049841.12 € | 520000.00 € | -916137.50 € | 653703.62 € | -1479018.88 €
6 | 300 | 1799727.63 € | 970000 | -916137.50 € | 1853590.13 € | 374571.25 €

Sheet: Versão 2
Custos de Fabricação ResQSense
(x1) Montioring Vest |  |  |  |  |  | (x1) Dashboard Tablet
Notas | Componente | Descrição | Qtd. | Preço |  | Notas | Componente | Descrição | Qtd. | Preço
Comprar só o chip e fazer a placa | ESP32-S3 Wroom 1 N8R8 | MCU | 1 | 11.90 € |  |  | Raspberry PI3 Model B+ | MCU | 1 | 39.86 €
 | TMP117 | Temperatura | 3 | 9.86 € |  | Poderia ser outo touchscreen | SC0880 | Touchscreen | 1 | 66.90 €
Comprar só o sensor smd PPG | SEN0344 | PPG | 1 | 13.58 € |  |  | BNO085 | IMU 9 eixos | 1 | 24.95 €
 | MPU6050 | IMU | 1 | 8.70 € |  |  | PC81.07.0100A.DB | Antena LoRa | 1 | 6.67 €
 | DFR1103 | GNSS | 1 | 22.11 € |  |  | RECE.20279.001E.01 | Conector Antena | 1 | 1.05 €
 | DWM3000TR13 | UWB | 1 | 23.11 € |  |  | Adafruit RFM95W | LoRa Transciever | 1 | 19.95 €
 | PC81.07.0100A.DB | Antena LoRa | 1 | 6.67 € |  |  | Speaker 8ohm | - | 1 | 8.50 €
 | RECE.20279.001E.01 | Conector Antena | 1 | 1.05 € |  |  | BC547C | BJT NPN | 1 | 0.05 €
 | Adafruit RFM95W | LoRa Transciever | 1 | 19.95 € |  |  | BC557C | BJT PNP | 1 | 0.05 €
 | FSR406 | "SOS Button" | 1 | 12.40 € |  |  | Bobine | Bobine | 1 | 1.50 €
 | TLV75733PDBVR | LDO Regulator | 1 | 0.33 € |  |  | LiFePo4 7,4v 10Ah | Bateria | 1 | 35.00 €
 | TPS2113APWR | Power Mux | 1 | 2.64 € |  |  | BMS | p/ carregar bateria | 1 | 10.00 €
 | MF52A2103J3470 | Thermístor NTC | 1 | 0.32 € |  |  | Filamentos | p/ Impressão 3D | 1 | 15.00 €
Comprar outro para uma LiFePo4 | Adafruit MAX17048 | Fuel Gauge | 1 | 5.95 € |  | Valor Aproximado | Extra Resistors | - | 1 | 5.00 €
Valor Aprox | LiFePo4 3,7v 1Ah | Bateria Principal | 1 | 10.00 € |  | Valor Aproximado | Extra Capacitors | - | 1 | 8.00 €
Outra bateria sem ser de lítio | 2CR5 | Bateria Backup | 1 | 6.40 € |  | 1 design (5 placas) = 5,00 | PCB Manufacturing | - | 1 | 5.00 €
 | VN2222 | MOSFETs | 2 | 0.68 € |  |  | Portes de Envio | - | 1 | 20.00 €
Valor Aproximado | Extra Resistors | - | 1 | 5.00 € |  | TOTAL: |  |  |  | 267.48 €
Valor Aproximado | Extra Capacitors | - | 1 | 8.00 €
1 design (5 placas) = 5,00 | PCB Manufacturing | - | 5 | 5.00 €
 | Portes de Envio | - | 1 | 20.00 €
 | Tecido | - | 1 | 50.00 €
TOTAL: |  |  |  | 284.05 €
Kit de Intervenção: 5 Monitoring Vest + 1 Dashboard Tablet
Custo Componentes 1 Kit: | 1687.73 €
Custos de Montagem: | 253.16 €
Custos de Packaging: | 150.00 €
Custos de Transporte e Logística: | 50.00 €
Margem de Erro (5%): | 84.39 €
CUSTO TOTAL DE 1 KIT: | 2225.28 €
Outros Custos
Nome | Periodicidade | Qtd. | Valor
Infraestrutura
Água | p/ano | 1 | 600.00 €
Luz | p/ano | 1 | 2400.00 €
Gás | p/ano | 1 | 400.00 €
Escritório (Renda) | p/ano | 1 | 15000.00 €
Internet & Hosting | p/ano | 1 | 1200.00 €
Impressora 3D e Ferramentas | p/ano | 1 | 3500.00 €
Deslocações | p/ano | 1 | 15000.00 €
Pessoal (R&D e Gestão)
Engenheiros | p/ano | 8 | 37200.00 €
Team Leaders | p/ano | 3 | 54000.00 €
CTO | p/ano | 1 | 72000.00 €
Marketing | p/ano | 1 | 57600.00 € |  |  |  |  | tecnicos (1ano)
 |  |  |  |  |  |  |  | Salariox1.7x12
Pessoal (Crescimento da Empresa - após o 3º ano) |  |  |  |  |  |  |  | garantias
Apoio ao Cliente | p/ano | 1 | 25000.00 € |  |  |  |  | engenheiros no 3 ou assim
Montagem | p/ano | 2 | 28000.00 €
Engenheiros Junior | p/ano | 2 | 32400.00 €
Outros
Working Captial | p/ano | 10% | 50000.00 €
Imprevistos | p/ano | 10% | 70000.00 €
Manutenção | p/ano | 1 | 10000.00 €
(Primeiros Anos) TOTAL: |  |  | 649300.00 €
(Após 3º Ano) TOTAL: |  |  | 795100.00 €
Modelo de Negócio e Estrutura de Receitas
Modelo de Negócio
A Wearion adota um modelo de negócio B2B Hibrido: A venda inicial do Hardware assegura uma receita imediata (CAPEX) e posteriormente o modelo HaaS garante umfluxo de receita recorrente (OPEX).
ResQSense (CAPEX) | Para o ResQSense (Kit), a Wearion establece parcerias com fabricantes de EPIs nacionalmente (e a nível europeu) conhecidos. Ao atribuir uma comissão de 15% sobre a venda, a Wearion garante uma penetração de mercado acelerada e preços competitivos, eliminando a necessidade de um elevado CAC (Customer Acquisition Cost).
 | Lucro ResQSense
 | Item | Valor |  |  |  | Tabela de Comparação de Custos (por Bombeiro)
 | Custo de Produção do Kit | 2225.28 € |  |  |  | Equipamento | Custo Estatístico
 | Preço de Venda (B2B) | 7500.00 € |  |  |  | Fato Nomex Completo | 927.00 €
 | Comissão p/ Parceiros (15%) | -1125.00 € |  |  |  | Câmera Térmica | 1057.00 €
 | Receita Líquida: | 6375.00 € |  |  |  | Botas Profissionais | 150.00 €
 | Lucro Bruto p/ Kit: | 4149.72 € |  |  |  | Kit ResQSense (Custo Médio) | 1250.00 €
 | Margem de Lucro: | 55.33%
 |  |  |  |  |  | Nota: O Custo Médio do Kit ResQSense é calculado fazendo uma média por cada dispositivo
HaaS (OPEX) | Para o HaaS, a Wearion pensa em fronecer os seguintes serviços: Basic Data Cloud; Training Analysis; Preventive Maintenance; Command App. Para ajudar a reter o cliente, o pacote Basic Data Cloud era oferecido no primeiro ano após a compra.
 | Serviço | Descrição | Preço de Venda p/ano | Custo p/ano | Margem Bruta | Taxa de Adesão
 | Basic Data Cloud | Sincronização em tempo real e armazenamento de dados de alertas na Cloud | 240.00 € | 120.00 € | 50% | 100%
 | Training Analysis | Armazenamento dos dados completos da missão e relatórios de performance pós-missão. | 720.00 € | 250.00 € | 65.27777778% | 50%
 | Preventive Maintenance | Verificação de integridade dos sensores/baterias e a substituição proativa. | 780.00 € | 450.00 € | 42.30769231% | 40%
 | Command App | Licenciamento para monitorização global de múltiplas equipas. | 1800.00 € | 500.00 € | 72.22222222% | 10%
Cumulative Cash Flow
Ano | Kits Vendidos | Lucro Hardware | Lucro HaaS | Custos | Fluxo de Caixa Anual | Fluxo Acumulado
0 | 0 | 0.00 € | 0.00 € | -50000.00 € | -50000.00 € | -50000.00 €
1 | 10 | 41497.24 € | 8520.00 € | -649300.00 € | -599282.76 € | -649282.76 €
2 | 25 | 103743.10 € | 32220.00 € | -649300.00 € | -513336.90 € | -1162619.66 € | IBERIA
3 | 50 | 207486.20 € | 80820.00 € | -795100.00 € | -506793.80 € | -1669413.46 €
4 | 75 | 311229.30 € | 156720.00 € | -795100.00 € | -327150.70 € | -1996564.16 €
5 | 100 | 414972.40 € | 259920.00 € | -795100.00 € | -120207.60 € | -2116771.76 €
6 | 125 | 518715.50 € | 390420.00 € | -795100.00 € | 114035.50 € | -2002736.26 €
7 | 150 | 622458.60 € | 537300.00 € | -795100.00 € | 364658.60 € | -1638077.66 €
8 | 200 | 829944.80 € | 743700.00 € | -795100.00 € | 778544.80 € | -859532.86 €
9 | 250 | 1037431.00 € | 1004700.00 € | -795100.00 € | 1247031.00 € | 387498.14 € | Expandir para o mercado Europeu?
10 | 300 | 1244917.20 € | 1320300.00 € | -795100.00 € | 1770117.20 € | 2157615.34 €

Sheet: Versão 3
Custos de Fabricação ResQSense
(x1) Montioring Vest |  |  |  |  |  | (x1) Dashboard Tablet
Notas | Componente | Descrição | Qtd. | Preço |  | Notas | Componente | Descrição | Qtd. | Preço
Comprar só o chip e fazer a placa | ESP32-S3 Wroom 1 N8R8 | MCU | 1 | 11.90 € |  |  | Raspberry PI3 Model B+ | MCU | 1 | 39.86 €
 | TMP117 | Temperatura | 3 | 9.86 € |  | Poderia ser outo touchscreen | SC0880 | Touchscreen | 1 | 66.90 €
Comprar só o sensor smd PPG | SEN0344 | PPG | 1 | 13.58 € |  |  | BNO085 | IMU 9 eixos | 1 | 24.95 €
 | MPU6050 | IMU | 1 | 8.70 € |  |  | PC81.07.0100A.DB | Antena LoRa | 1 | 6.67 €
 | DFR1103 | GNSS | 1 | 22.11 € |  |  | RECE.20279.001E.01 | Conector Antena | 1 | 1.05 €
 | DWM3000TR13 | UWB | 1 | 23.11 € |  |  | Adafruit RFM95W | LoRa Transciever | 1 | 19.95 €
 | PC81.07.0100A.DB | Antena LoRa | 1 | 6.67 € |  |  | Speaker 8ohm | - | 1 | 8.50 €
 | RECE.20279.001E.01 | Conector Antena | 1 | 1.05 € |  |  | BC547C | BJT NPN | 1 | 0.05 €
 | Adafruit RFM95W | LoRa Transciever | 1 | 19.95 € |  |  | BC557C | BJT PNP | 1 | 0.05 €
 | FSR406 | "SOS Button" | 1 | 12.40 € |  |  | Bobine | Bobine | 1 | 1.50 €
 | TLV75733PDBVR | LDO Regulator | 1 | 0.33 € |  |  | LiFePo4 7,4v 10Ah | Bateria | 1 | 35.00 €
 | TPS2113APWR | Power Mux | 1 | 2.64 € |  |  | BMS | p/ carregar bateria | 1 | 10.00 €
 | MF52A2103J3470 | Thermístor NTC | 1 | 0.32 € |  |  | Filamentos | p/ Impressão 3D | 1 | 15.00 €
Comprar outro para uma LiFePo4 | Adafruit MAX17048 | Fuel Gauge | 1 | 5.95 € |  | Valor Aproximado | Extra Resistors | - | 1 | 5.00 €
Valor Aprox | LiFePo4 3,7v 1Ah | Bateria Principal | 1 | 10.00 € |  | Valor Aproximado | Extra Capacitors | - | 1 | 8.00 €
Outra bateria sem ser de lítio | 2CR5 | Bateria Backup | 1 | 6.40 € |  | 1 design (5 placas) = 5,00 | PCB Manufacturing | - | 1 | 5.00 €
 | VN2222 | MOSFETs | 2 | 0.68 € |  |  | Portes de Envio | - | 1 | 20.00 €
Valor Aproximado | Extra Resistors | - | 1 | 5.00 € |  | TOTAL: |  |  |  | 267.48 €
Valor Aproximado | Extra Capacitors | - | 1 | 8.00 €
1 design (5 placas) = 5,00 | PCB Manufacturing | - | 5 | 5.00 €
 | Portes de Envio | - | 1 | 20.00 €
 | Tecido | - | 1 | 50.00 €
TOTAL: |  |  |  | 284.05 €
Kit de Intervenção: 5 Monitoring Vest + 1 Dashboard Tablet
Custo Componentes 1 Kit: | 1687.73 €
Custos de Montagem: | 253.16 €
Custos de Packaging: | 150.00 €
Custos de Transporte e Logística: | 50.00 €
Margem de Erro (5%): | 84.39 €
CUSTO TOTAL DE 1 KIT: | 2225.28 €
Outros Custos
Nome | Periodicidade | Qtd. | Valor
Infraestrutura
Água | p/ano | 1 | 600.00 €
Luz | p/ano | 1 | 2400.00 €
Gás | p/ano | 1 | 400.00 €
Escritório (Renda) | p/ano | 1 | 15000.00 €
Internet & Hosting | p/ano | 1 | 1200.00 €
Impressora 3D e Ferramentas | p/ano | 1 | 3500.00 €
Deslocações | p/ano | 1 | 15000.00 €
Pessoal (R&D e Gestão)
Engenheiros | p/ano | 0 | 37200.00 €
Team Leaders | p/ano | 2 | 54000.00 €
CTO | p/ano | 1 | 72000.00 €
Marketing | p/ano | 1 | 57600.00 € |  |  |  |  | tecnicos (1ano)
 |  |  |  |  |  |  |  | Salariox1.7x12
Pessoal (Crescimento da Empresa - após o 3º ano) |  |  |  |  |  |  |  | garantias
Apoio ao Cliente | p/ano | 1 | 25000.00 € |  |  |  |  | engenheiros no 3 ou assim
Montagem | p/ano | 2 | 28000.00 €
Engenheiros Junior | p/ano | 5 | 32400.00 €
Outros
Working Captial | p/ano | 10% | 50000.00 €
Imprevistos | p/ano | 10% | 70000.00 €
Manutenção | p/ano | 1 | 10000.00 €
(Primeiros Anos) TOTAL: |  |  | 297700.00 €
(Após 3º Ano) TOTAL: |  |  | 540700.00 €
Modelo de Negócio e Estrutura de Receitas
Modelo de Negócio
A Wearion adota um modelo de negócio B2B Hibrido: A venda inicial do Hardware assegura uma receita imediata (CAPEX) e posteriormente o modelo HaaS garante umfluxo de receita recorrente (OPEX).
ResQSense (CAPEX) | Para o ResQSense (Kit), a Wearion establece parcerias com fabricantes de EPIs nacionalmente (e a nível europeu) conhecidos. Ao atribuir uma comissão de 15% sobre a venda, a Wearion garante uma penetração de mercado acelerada e preços competitivos, eliminando a necessidade de um elevado CAC (Customer Acquisition Cost).
 | Lucro ResQSense
 | Item | Valor |  |  |  | Tabela de Comparação de Custos (por Bombeiro)
 | Custo de Produção do Kit | 2225.28 € |  |  |  | Equipamento | Custo Estatístico
 | Preço de Venda (B2B) | 7500.00 € |  |  |  | Fato Nomex Completo | 927.00 €
 | Comissão p/ Parceiros (15%) | -1125.00 € |  |  |  | Câmera Térmica | 1057.00 €
 | Receita Líquida: | 6375.00 € |  |  |  | Botas Profissionais | 150.00 €
 | Lucro Bruto p/ Kit: | 4149.72 € |  |  |  | Kit ResQSense (Custo Médio) | 1250.00 €
 | Margem de Lucro: | 55.33%
 |  |  |  |  |  | Nota: O Custo Médio do Kit ResQSense é calculado fazendo uma média por cada dispositivo
HaaS (OPEX) | Para o HaaS, a Wearion pensa em fronecer os seguintes serviços: Basic Data Cloud; Training Analysis; Preventive Maintenance; Command App. Para ajudar a reter o cliente, o pacote Basic Data Cloud era oferecido no primeiro ano após a compra.
 | Serviço | Descrição | Preço de Venda p/ano | Custo p/ano | Margem Bruta | Taxa de Adesão
 | Basic Data Cloud | Sincronização em tempo real e armazenamento de dados de alertas na Cloud | 240.00 € | 120.00 € | 50% | 100%
 | Training Analysis | Armazenamento dos dados completos da missão e relatórios de performance pós-missão. | 720.00 € | 250.00 € | 65.27777778% | 50%
 | Premium Care | Verificação de integridade dos sensores/baterias e a substituição proativa. | 780.00 € | 450.00 € | 42.30769231% | 40%
 | Command App | Licenciamento para monitorização global de múltiplas equipas. | 1800.00 € | 500.00 € | 72.22222222% | 10%
Cumulative Cash Flow
Ano | Sistemas Vendidos | Lucro Hardware | Lucro HaaS | Custos | Fluxo de Caixa Anual | Fluxo Acumulado
0 | 0 | 0.00 € | 0.00 € | -50000.00 € | -50000.00 € | -50000.00 €
1 | 10 | 41497.24 € | 8520.00 € | -297700.00 € | -247682.76 € | -297682.76 €
2 | 25 | 103743.10 € | 32220.00 € | -297700.00 € | -161736.90 € | -459419.66 € | IBERIA
3 | 50 | 207486.20 € | 80820.00 € | -540700.00 € | -252393.80 € | -711813.46 €
4 | 75 | 311229.30 € | 156720.00 € | -540700.00 € | -72750.70 € | -784564.16 €
5 | 100 | 414972.40 € | 259920.00 € | -540700.00 € | 134192.40 € | -650371.76 €
6 | 125 | 518715.50 € | 390420.00 € | -540700.00 € | 368435.50 € | -281936.26 €
7 | 150 | 622458.60 € | 537300.00 € | -540700.00 € | 619058.60 € | 337122.34 €
8 | 200 | 829944.80 € | 743700.00 € | -540700.00 € | 1032944.80 € | 1370067.14 €
9 | 250 | 1037431.00 € | 1004700.00 € | -540700.00 € | 1501431.00 € | 2871498.14 € | Expandir para o mercado Europeu?
10 | 300 | 1244917.20 € | 1320300.00 € | -540700.00 € | 2024517.20 € | 4896015.34 €

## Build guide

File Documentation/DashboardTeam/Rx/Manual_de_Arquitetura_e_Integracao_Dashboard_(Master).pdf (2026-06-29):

# Manual de Arquitetura e Integração: Dashboard (Master)

Projeto Wearion- ResQSense

Data - 16/02/2026

Autor- Dinis

## 1. Visão Geral do Sistema (Lado do Tablet)

Este relatório documenta a infraestrutura de software desenvolvida para o Tablet.

Na arquitetura de rede do ResQSense, o Tablet assume o papel de Master. O seu principal objetivo não é apenas apresentar dados, mas também gerir ativamente a rede LoRa: registar os dispositivos na rede, atribuir janelas de tempo de transmissão aos coletes (para isso usamos o protocolo TDMA) para evitar colisões, e garantir a desencriptação em tempo real do dados recebidos.

## 2. Ferramentas e Bibliotecas usadas (Python)

Para o Raspberry Pi conseguir comunicar com a rede de sensores, é necessário fazer uma transição da lógica do C++ para um ambiente Python. Para a implementação deste módulo em Python, vão ser usadas as seguintes bibliotecas:

adafruit-circuitpython-rfm9x : Esta biblioteca faz a ligação SPI entre o sistema Linux e o rádio LoRa SX1276. Além disso, a potência de emissão vai ser limitada aos 14 dBm diretamente no código, para garantirmos que respeitamos as regras europeias (ETSI EN 300 220) para a banda dos 868 MHz.

pycryptodome: Assegura a leitura dos pacotes encriptados nativamente pela biblioteca mbedtls do lado do hardware.

Manual de Arquitetura e Integração: Dashboard (Master) | 1

struct: É uma biblioteca nativa, usada para empacotar e desempacotar os bytes de informação. Usamos isto para que o código imite a forma como o microcontrolador (em C++) organiza a memoria.

## 3. Camada de Segurança e Sincronização (TDMA)

Para que o Python do tablet e o hardware do colete consigam entender-se e mantenham os dados seguros, implementámos o algoritmo AES-128. Escolhemos o modo ECB (Electronic Codebook) porque este modo tranforma 16 bytes limpos noutros 16 bytes limpos, sem adicionar vetores de inicialização extras que iam estragar o tamanho limite do nosso pacote. A chave privada da equipa será definida como um array de bytes no código.

Sempre que o Comandante adiciona um bombeiro na interface gráfica, o sistema calcula um atraso temporal (offset) com base no Slot que lhe foi atribuido (ex: slot*1500ms). Esse valor é empacotado e enviado num pacote de controlo (indentificado por exemplo com o byte 0xC1). Para garantir que nada falha, o tablet só dá o registo como concluído no ecrã quando recebe do colete um pacote de confirmação (0xC2).

## 4. Leitura e separação dos dados vitais

Neste codigo temos uma função que está sempre a ouvir o rádio. Quando deteta um pacote que não é de controlo, desempacota os dados desse pacote (dados vitais). Ao usarmos a formatação <bBHhiih da biblioteca struct, conseguimos pegar nos 16 bytes e convertê-los em variáveis que o código Python consegue ler e processar.

Para otimizar a largura de banda e manter o pacote de rádio o mais leve possível, o firmware do colete agrupa duas informações cruciais no mesmo byte (a variável spo2_header). O primeiro bit à esquerda guarda o estado de Alerta (SOS/Man Down) e os 7 bits restantes guardam a percentagem de oxigénio (SpO2).

Para o Python conseguir separar a informação e ler cada valor individualmente, são feitas as seguintes operações:

Para extrair o Alerta (>>7 e & 0x01): Como o alerta está na posição mais à esquerda, o comando >>7 empurra os dados 7 "casas" para a direita, ficando com o alerta no bit mais à direita. A máscara & 0x01 serve como um filtro final que ignora o resto da informação, devolvendo-nos um valor
de 1 (Perigo) ou 0 (Normal).

Para extrair o SpO2 (& 0x7F): Neste caso fazemos o inverso. Usamos a máscara 0x7F (01111111 em binário) para apagar o bit de alerta. Desta forma forçamos o bit do alerta a zero, e mantemos os outros 7 bits intactos. O número que sobra é o valor exato da saturação de oxigénio.

Ajuste das casas decimais: Enviar números com vírgulas (floats) gasta demasiada memória de rádio. Por isso, o colete multiplica a temperatura por 100 (ex: 36.50ºC é enviado na forma 3650) e envia os valores como números inteiros. Após isso vamos pegar nesses números recebidos e dividi-los pelos mesmos multiplicadores para voltarmos a ter as casas decimais corretas no ecrã.

## 5. Ligação à Interface Gráfica

O próximo passo prático será ligar a função que recebe os dados (listen_for_incoming_data) ao ecrã visual do Tablet. Para evitar que a interface fique bloqueada enquanto o rádio está à espera de pacotes, temos que colocar este processo a correr em segundo plano (threads). Isto garante que o dashboard responde sempre aos toques e consegue destacar instantaneamente um bombeiro a vermelho mal chegue um sinal de perigo.

### 6. Como funciona o Código (Comunication.py)

6.1 Inicialização e Configuração do Módulo LoRa

CS = digitalio.DigitalInOut(board.CE1)
RESET = digitalio.DigitalInOut(board.D25)
spi = busio.SPI(board.SCK, MOSI=board.MOSI, MISO=board.MIS O)

try:
# Inicializar a 868 MHz (Banda ISM Europeia)

lora = RFM9x(spi, CS, RESET, 868.0)
# Limitar a potência a 14 dBm para cumprir a lei (ETSI

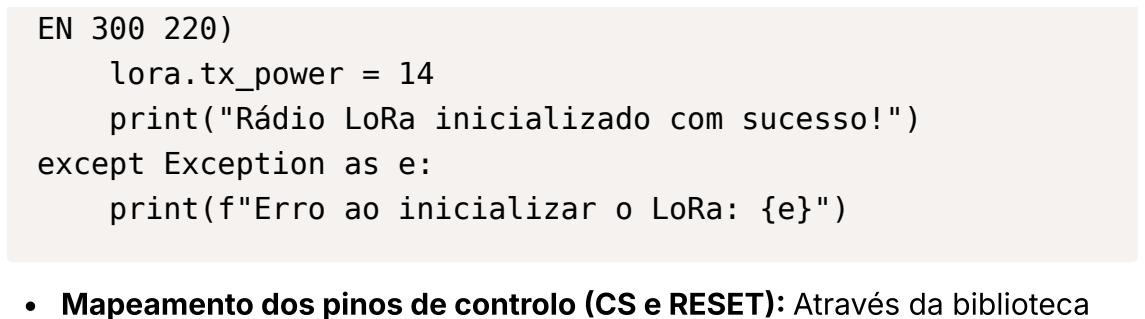
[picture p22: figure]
EN 300 220) lora.tx_power = 14 print("Rádio LoRa inicializado com sucesso!") except Exception as e:

print(f"Erro ao inicializar o LoRa: {e}")

Mapeamento dos pinos de controlo (CS e RESET): Através da biblioteca digitalio, definimos os pinos que vão gerir o estado da antena. O pino do Chip Select (CE1) é usado para avisar o módulo de que o Raspberry Pi vai lhe enviar comandos, enquanto o pino de Reset (D25) garante que o chip é reiniciado e limpa sempre que o nosso código arranca, desta forma prevenimos falhas na memória resultantes de utilizações anteriores.

Protocolo de Comunicação SPI: Ao configurar a variável spi, ativamos o sinal de relógio (Clock) e os canais de entrada e saída de dados
(MISO e MOSI). Isto abre um canal que garante uma transferência rápida e estável dos nossos pacotes de 16 bytes entre o Raspberry Pi e o rádio.

Configuração da Frequência e da Potência de Emissão: Assim que ativamos o módulo LoRa, colocamo-lo a trabalhar nos 868.0 MHz. Logo na linha seguinte, limitamos a força do sinal a 14 dBm (25 mW). Isto é importante implementar no código para garantir que o projeto funciona dentro da legalidade europeia (ETSI EN 300 220) para esta banda de rádio livre.

6.2 Criação do pacote de controlo

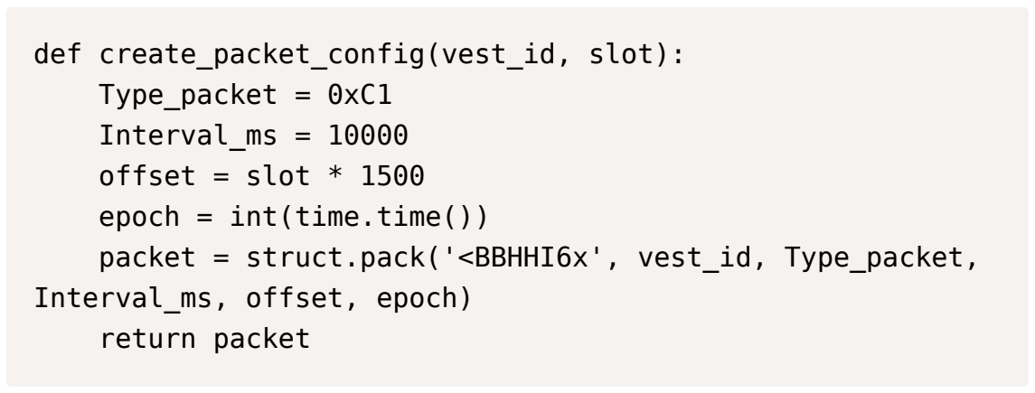
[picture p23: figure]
def create_packet_config(vest_id, slot): Type_packet = 0xC1 Interval_ms = 10000 offset = slot * 1500 epoch = int(time.time()) packet = struct.pack('<BBHHI6x', vest_id, Type_packet, Interval_ms, offset, epoch) return packet

O prefixo ’<’ obriga o Python a usar a memória em formato Little-endian, porque se não o fizermos, o microcontrolador vai receber e ler os números todos trocados. O sufixo ’6x’ no final serve simplesmente para encher o resto do pacote com zeros (padding), obrigando-o a ter os 16 bytes. (Explicação mais detalhada no documento "Comunication.py V1”)

6.3 Desconstruir a Mensagem do Colete

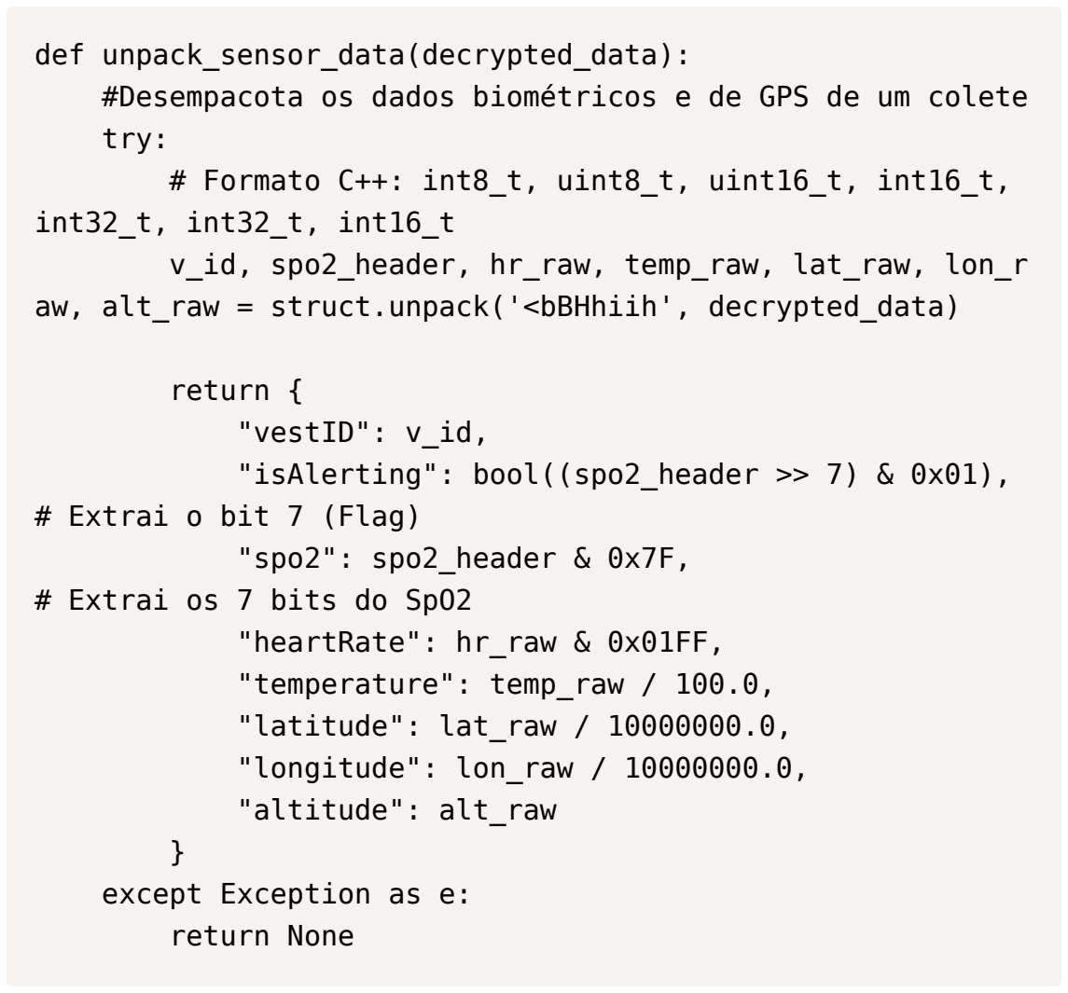
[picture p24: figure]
def unpack_sensor_data(decrypted_data):; try:; int32_t, int32_t, int16_t; aw, alt_raw = struct.unpack('<bBHhiih', decrypted_data); return { "vestID": v_id,; # Extrai o bit 7 (Flag) "spo2": spo2_header & 0x7F, # Extrai os 7 bits do SpO2 "heartRate": hr_raw & 0x01FF, "temperature": temp_raw / 100.0, "latitude": lat_raw / 10000000.0, "longitude": lon_raw / 10000000.0, "altitude": alt_raw; } except Exception as e: return None

#Desempacota os dados biométricos e de GPS de um colete

# Formato C++: int8_t, uint8_t, uint16_t, int16_t,

v_id, spo2_header, hr_raw, temp_raw, lat_raw, lon_r

"isAlerting": bool((spo2_header >> 7) & 0x01),

Aplicamos a máscara '<bBHhiih’ aos bytes desencriptados. O Python corta automaticamente o bloco nas 7 variáveis originais criadas pelo hardware.

<bBHhiih :

'b’, ID do colete (8 bits com sinal).

'B’, Contém o SpO2 e o Alerta (8 bits sem sinal)

‘H', Batimento cardíaco (16 bits sem sinal).

‘h', Temperatura (16 bits com sinal)

‘i, Latitude e Longitude (32 bits com sinal cada)

'i’, Altitude (16 bits com sinal)

6.4 Encriptação e Segurança (AES-128 ECB)

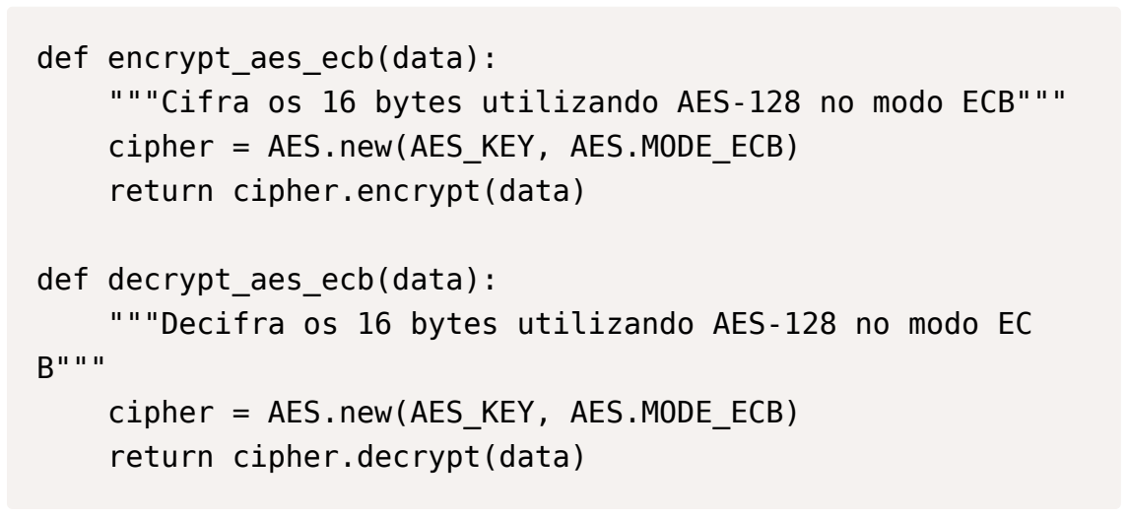
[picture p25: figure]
def encrypt_aes_ecb(data):; cipher = AES.new(AES_KEY, AES.MODE_ECB) return cipher.encrypt(data); def decrypt_aes_ecb(data):; cipher = AES.new(AES_KEY, AES.MODE_ECB) return cipher.decrypt(data)

"""Cifra os 16 bytes utilizando AES-128 no modo ECB"""

"""Decifra os 16 bytes utilizando AES-128 no modo EC

Neste código é utilizada uma chave simétrica de 16 bytes que é partilhada pelo Master e pelos Slaves(AES_KEY).

O Modo de encriptação implementado é o modo ECB que foi escolhido porque cifra blocos de 16 bytes sem adicionar overhead (como os Vetores de Inicialização exigidos noutros modos).Isto garante que a mensagem por rádio se mantenha compacta e rápida de transmitir, poupando bateria.

6.5 Protocolo de Handshake e Sincronização (ACK)

def wait_for_ack(expected_vest_id, timeout=5.0): start_time = time.time()
while (time.time() - start_time) < timeout: packet = lora.receive(timeout=0.5)
if packet is not None and len(packet) == 16: decrypted = decrypt_aes_ecb(packet)
try:
source_id, p_type, status, battery = struc t.unpack('<BBBB12x', decrypted) if p_type == 0xC2 and source_id == expected _vest_id:

if status == 1:
print(f"Sucesso: Colete {source_id} sincronizado! Bateria: {battery}%") return True
except:
pass
print(f"Erro: Timeout ao configurar colete {expected_ve st_id}.")
return False

Após enviar o pacote 0xC1 através da função send_cofiguration, o código entra nesta função e fica à escuta durante 5 segundos.Se receber um pacote, tenta decifrá-lo e verifica se o tipo de pacote(p_type) é 0xC2 (que significa Confirmação/ACK).Esta função só retorna True (diz à Interface Gráfica que pode “desenhar” o bombeiro no ecrã) se o ID do colete bater certo com o esperado e se o estado for de sucesso (status==1). Caso contrário, dá Timeout.

6.6 Motor de escuta contínua e Processamento em segundo plano

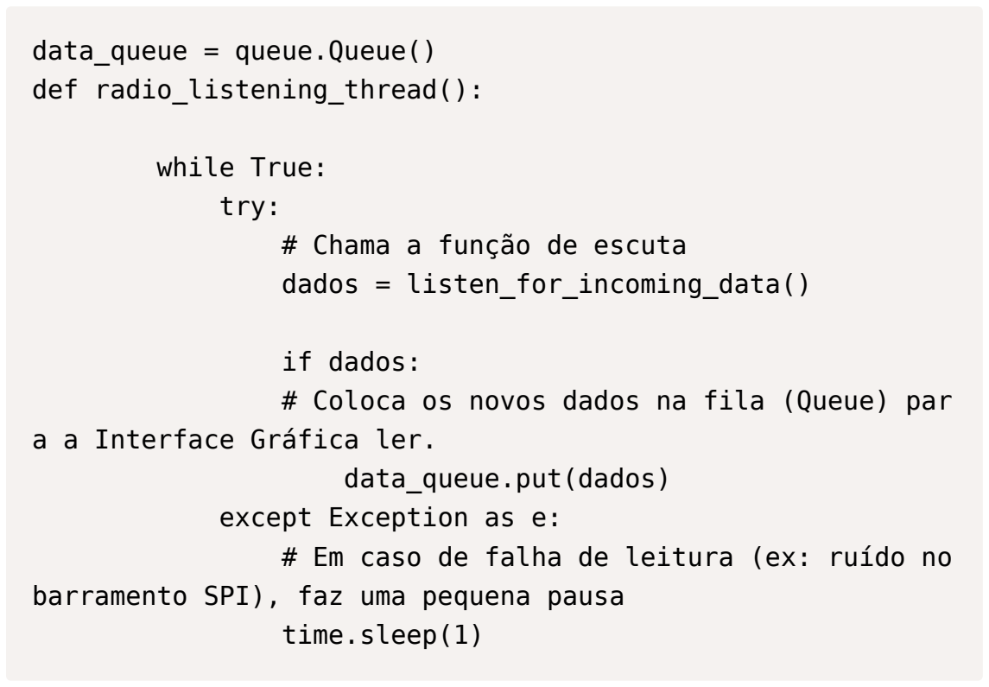
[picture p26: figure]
data_queue = queue.Queue() def radio_listening_thread():; while True: try:; # Chama a função de escuta dados = listen_for_incoming_data(); if dados:; a a Interface Gráfica ler. data_queue.put(dados) except Exception as e:; barramento SPI), faz uma pequena pausa time.sleep(1)

# Coloca os novos dados na fila (Queue) par

# Em caso de falha de leitura (ex: ruído no

Para garantir que a Interface Gráfica do Tablet funciona sem interrupções e bloqueios, o processo de escuta da rede LoRa foi colocado a correr em segundo plano (numa Background Thread). Este processo funciona num ciclo contínuo, onde recebe e decifra dados em tempo real sem interferir com o sistema principal. Além disso, no código foi implementado um mecanismo de proteção (try/except) que impede o programa de ir abaixo caso ocorram pequenas falhas de hardware.

6.7 Escuta Contínua e Processamento dos Dados Vitais

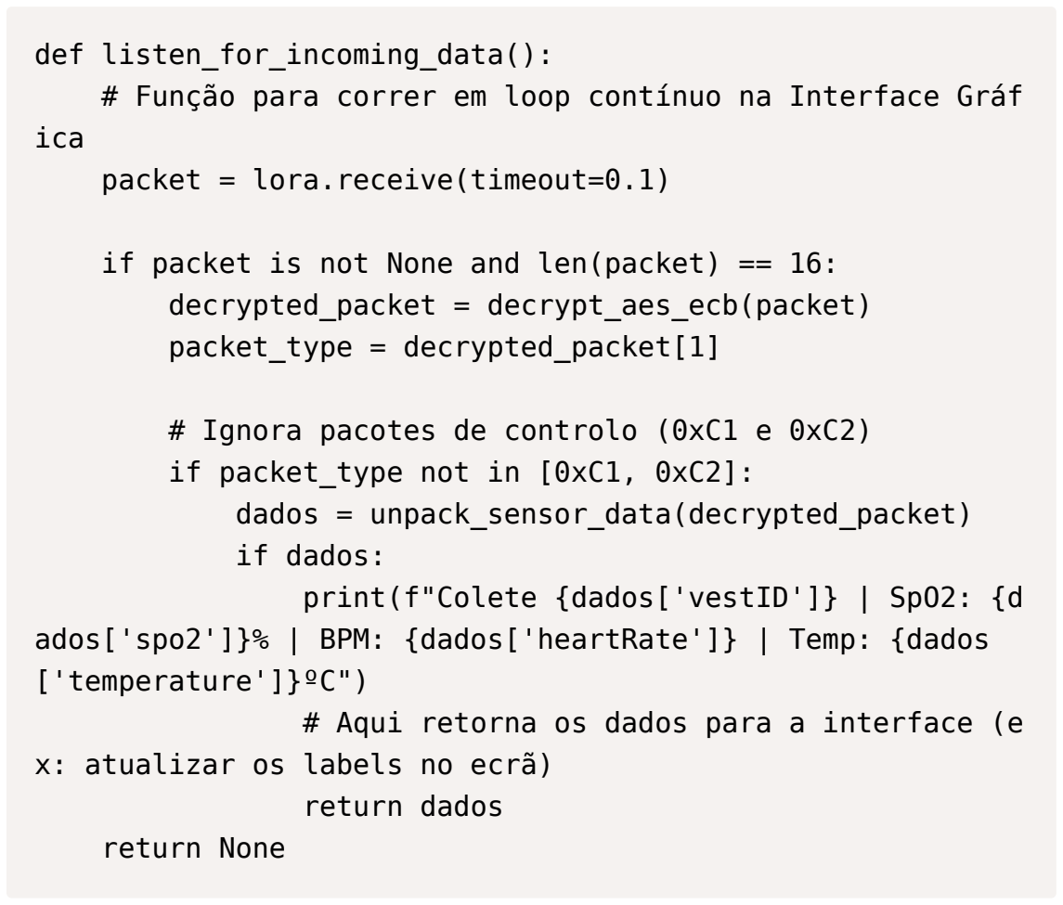
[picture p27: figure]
def listen_for_incoming_data():; ica; packet = lora.receive(timeout=0.1); decrypted_packet = decrypt_aes_ecb(packet) packet_type = decrypted_packet[1]; if packet_type not in [0xC1, 0xC2]: dados = unpack_sensor_data(decrypted_packet) if dados: print(f"Colete {dados['vestID']} | SpO2: {d; ['temperature']}ºC"); x: atualizar os labels no ecrã) return dados; return None

# Função para correr em loop contínuo na Interface Gráf

if packet is not None and len(packet) == 16:

# Ignora pacotes de controlo (0xC1 e 0xC2)

ados['spo2']}% | BPM: {dados['heartRate']} | Temp: {dados

# Aqui retorna os dados para a interface (e

A função “listen_for_incoming_data” é o principal ponto de receção de telemetria do Master. Ela é chamada continuamente por uma thread em segundo plano. Logo no início, a função faz uma verificação rápida do módulo de rádio, com um tempo de espera (timeout) de 0,1 segundos. Desta forma, o sistema consegue verificar o tráfego aéreo sem ficar bloqueado à espera de dados. Assim que um pacote é intercetado, o código confirma se ele tem exatamente 16 bytes, como exige o algoritmo AES-128 e, se tudo estiver correto, procede à sua desencriptação.A lógica central desta função está no seu filtro principal: ao analisar o segundo byte do pacote desencriptado, o sistema ignora propositadamente qualquer mensagem de configuração (0xC1) ou de confirmação (0xC2). A ideia é que esta rotina se concentre apenas na receção dos dados realmente importantes, sobretudo informação vital e de localização dos operacionais. Quando um pacote de telemetria passa por este filtro, o seu conteúdo é desempacotado e convertido num dicionário bem estruturado. No final, a função devolve esta informação já limpa, deixando os dados biométricos prontos para serem injetados e visualizados em tempo real na interface gráfica do utilizador.

6.8 Arranque do Sistema e Ponto de Entrada Principal

# ARRANQUE DO PROGRAMA

if __name__ == "__main__":

# 1. Pára a execução se o hardware do rádio falhar

if 'lora' not in globals():
print("O sistema não pode arrancar sem o módulo LoR a.")
exit(1)

# 2. Iniciar a Thread de escuta de dados

rx_thread = threading.Thread(target=radio_listening_thr ead, daemon=True)
rx_thread.start()

print("\n Serviço de comunicações a correr...") print("Ctrl+C para encerrar.\n")

# 3. Manter o script principal a correr

try:
while True:
# Aqui é onde vamos encaixar a Interface Gráfic a

time.sleep(1)

except KeyboardInterrupt:
print("\n Encerramento feito pelo utilizador.")

Este é o bloco final do código e funciona como o “motor de arranque” do sistema. É ele que orquestra tudo o que acontece a partir do momento em que executamos o ficheiro.
Logo no início é feito um teste de segurança: o sistema verifica se o módulo de rádio LoRa arrancou corretamente e se está disponível na memória. Se houver algum problema físico, como por exemplo um cabo SPI mal ligado no Raspberry Pi, o programa é imediatamente interrompido. Isto impede que o software tente comunicar com um rádio que não existe, o que poderia levar a bloqueios na aplicação.
Depois de confirmado que o módulo de rádio está operacional, é iniciada a escuta da rede, arrancando a thread de comunicações em segundo plano. De seguida, o script entra num ciclo contínuo de espera (while True), que, nesta fase, ainda está incompleto, pois é aqui que vamos ligar a interface gráfica.
Por último, foi incluída uma forma segura de desligar o sistema “KeyboardInterrupt”. Se for necessário parar o programa manualmente, ele termina tudo de forma limpa.

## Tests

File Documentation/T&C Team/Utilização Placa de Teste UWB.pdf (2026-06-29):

# PCB UWB

## 24 de junho de 2026

## 1 Hardware e Especificações

## 1.1 Descrição e Componentes

Abaixo encontra-se a tabela com a especificação dos componentes da placa:

Ref. | Componente | Valor / Part# | Função
IC1 | DWM3000TR13 | Qorvo | Módulo UWB completo (DW3000 + antena + crystal
| | | 38.4 MHz)
D1 | Zener 3.3V | 1N4728A ou eq. | Proteção sobre-tensão.
FB1 | Ferrite Bead | 600 Ω @ 100 MHz | Filtragem EMI na alimentação VDD3V3 do crystal
LED1 | LED PWR | Verde | Indica presença de 3.3V - sempre aceso quando
| | | alimentado
LED2 | LED TX | Amarelo | Pisca em cada transmissão UWB
LED3 | LED RX | Azul | Pisca em cada recepção UWB
R RST PU1 | Pull-up RST | 10 kΩ | Mantém RST em HIGH por defeito
R CS PU1 | Pull-up CS | 10 kΩ | Mantém CS em HIGH quando SPI inativo
R CS1 | Série CS | 33 Ω | Proteção linha SPI CS
R MOSI1 | Série MOSI | 33 Ω | Proteção linha SPI MOSI
R MISO1 | Série MISO | 22 Ω | Proteção linha SPI MISO
R CLK1 | Série CLK | 33 Ω | Proteção linha SPI CLK
R IRQ1 | Série IRQ | 22 Ω | Proteção linha IRQ
R WAKE1 | Série WAKE | 22 Ω | Proteção linha WAKEUP
R RST1 | Série RST | 1 kΩ | Proteção linha RST

## 1.2 Pinagem do Conector

Abaixo encontra-se a tabela com a pinagem na placa de teste PCB UWB:

Pino Sinal | Função | Notas
1 | GND | Massa
2 | EXTON | Monitor saída ext. Via R EXTON1 (22 Ω)
3 | WAKEUP Acordar do sleep | Pulso ≥ 600 µs
4 | +3V3 | Alimentação PCB | Fonte dos 3.3V do ESP32
5 | RST EN | Reset do DW3000 Via R RST1 (1 kΩ), pull-up 10 kΩ
6 | SYNC | Sincronização | Via R SYNC1 (100 kΩ pull-down)
7 | GND | Massa
8 | CS N | SPI Chip Select | Via R CS1 (33 Ω), pull-up 10 kΩ
9 | MOSI | SPI Data In | Via R MOSI1 (33 Ω)
10 | MISO | SPI Data Out | Via R MISO1 (22 Ω)
11 | CLK | SPI Clock | Via R CLK1 (33 Ω)
12 | IRQ | Interrupção | Via R IRQ1 (22 Ω)
13 | GND | Massa

## 1.3 LEDs de Estado e Pontos de Teste

LED | Cor | Quando Acende
LED PWR1 | Verde | Sempre que o PCB tem alimentação 3.3V
LED TX1 | Amarelo | Breve flash durante cada transmissão UWB
LED RX1 | Azul | Breve flash durante cada recepção UWB

Pontos de teste disponíveis para multímetro/osciloscópio: TP 3V3, TP GND, TP CS, TP MOSI, TP MISO, TP CLK, TP RST, TP IRQ, TP WAKE, TP EXTON, TP SYNC.

## 2 Ambiente de Desenvolvimento

## 2.1 Definições do Arduino IDE

Quaisquer desvios das definições abaixo testadas podem causar falhas de funcionamento.

Definição | Valor | Motivo
Board | ESP32S3 Dev Module | Board correta para ESP32-S3
PSRAM | OPI PSRAM | O hardware possui 8 MB PSRAM com interface OPI
Flash Size | 8MB (64Mb) | O hardware possui 8 MB flash
Flash Mode | QIO 80MHz | Modo rápido necessário
USB CDC On Boot | Disabled | Garante o correto direcionamento da Serial0 para a UART
CPU Frequency | 240 MHz | Máximo desempenho para timing UWB preciso
Upload Speed | 921600 | Upload rápido

## 2.2 Estrutura de Ficheiros do Projeto

Cada sketch (.ino) deve estar numa pasta própria com os ficheiros da biblioteca DW3000 copiados para dentro, sendo incluídos diretamente no código fonte:

- pasta codigo exemplo/

– codigo exemplo.ino

– dw3000.h

– dw3000 device api.h/.cpp

– dw3000 config options.h/.cpp

– dw3000 shared functions.h/.cpp

– dw3000 mac 802 15 4.h/.cpp

– dw3000 port.h/.cpp

– dw3000 mutex.cpp

– dw3000 uart.h/.cpp

– dw3000 regs.h, dw3000 vals.h, dw3000 types.h

– dw3000 shared defines.h, dw3000 version.h

## 3 Funcionamento dos Códigos Exemplo

O principal objetivo desta placa é servir de ambiente de testes para colocar o módulo UWB a operar rapidamente. Os três códigos de exemplo fornecidos são ferramentas de suporte para compreender o comportamento do módulo, testar a comunicação e servir de inspiração para futuros desenvolvimentos:

Papel | Firmware | Descrição
Initiator (Tag) iniciator v5...ino | Módulo a localizar. Mede a distância a R1 e R2 e calcula a posição
| | por interseção de círculos.
Responder R1 | responder v2 c1.ino | Ancora fixa em posição GPS conhecida. Responde apenas a ˆ | polls
| | com destino “R1”.
Responder R2 | responder v2 c2.ino | Segunda âncora fixa. Idêntica a R1, mas responde apenas a polls
| | com destino “R2”.

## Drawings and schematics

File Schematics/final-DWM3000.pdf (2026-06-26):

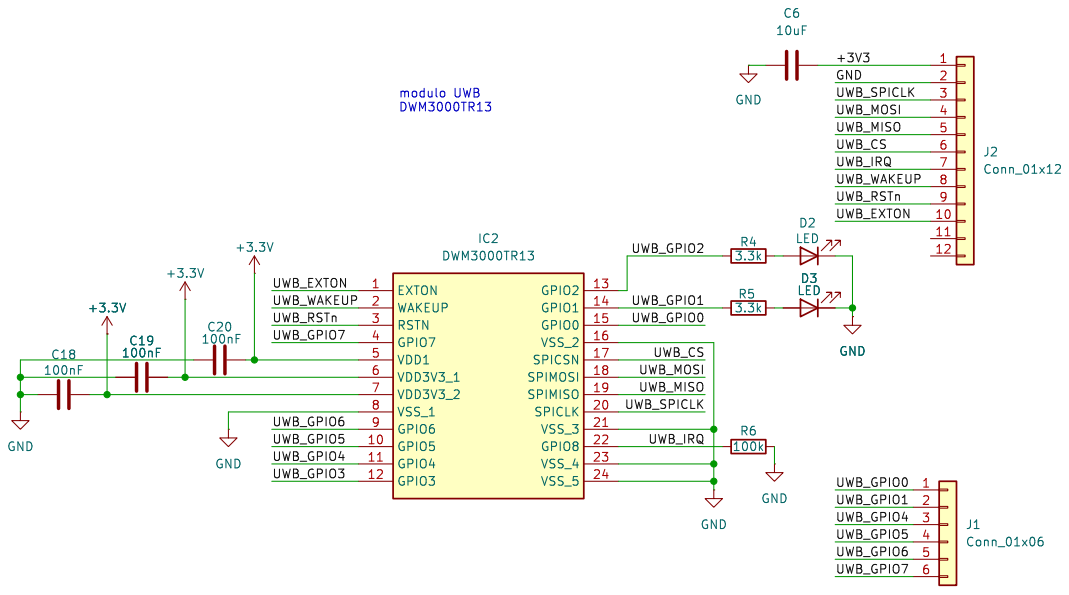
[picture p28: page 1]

Id: 4/13 Title: File: UWB.kicad_sch Sheet: /DWM3000/

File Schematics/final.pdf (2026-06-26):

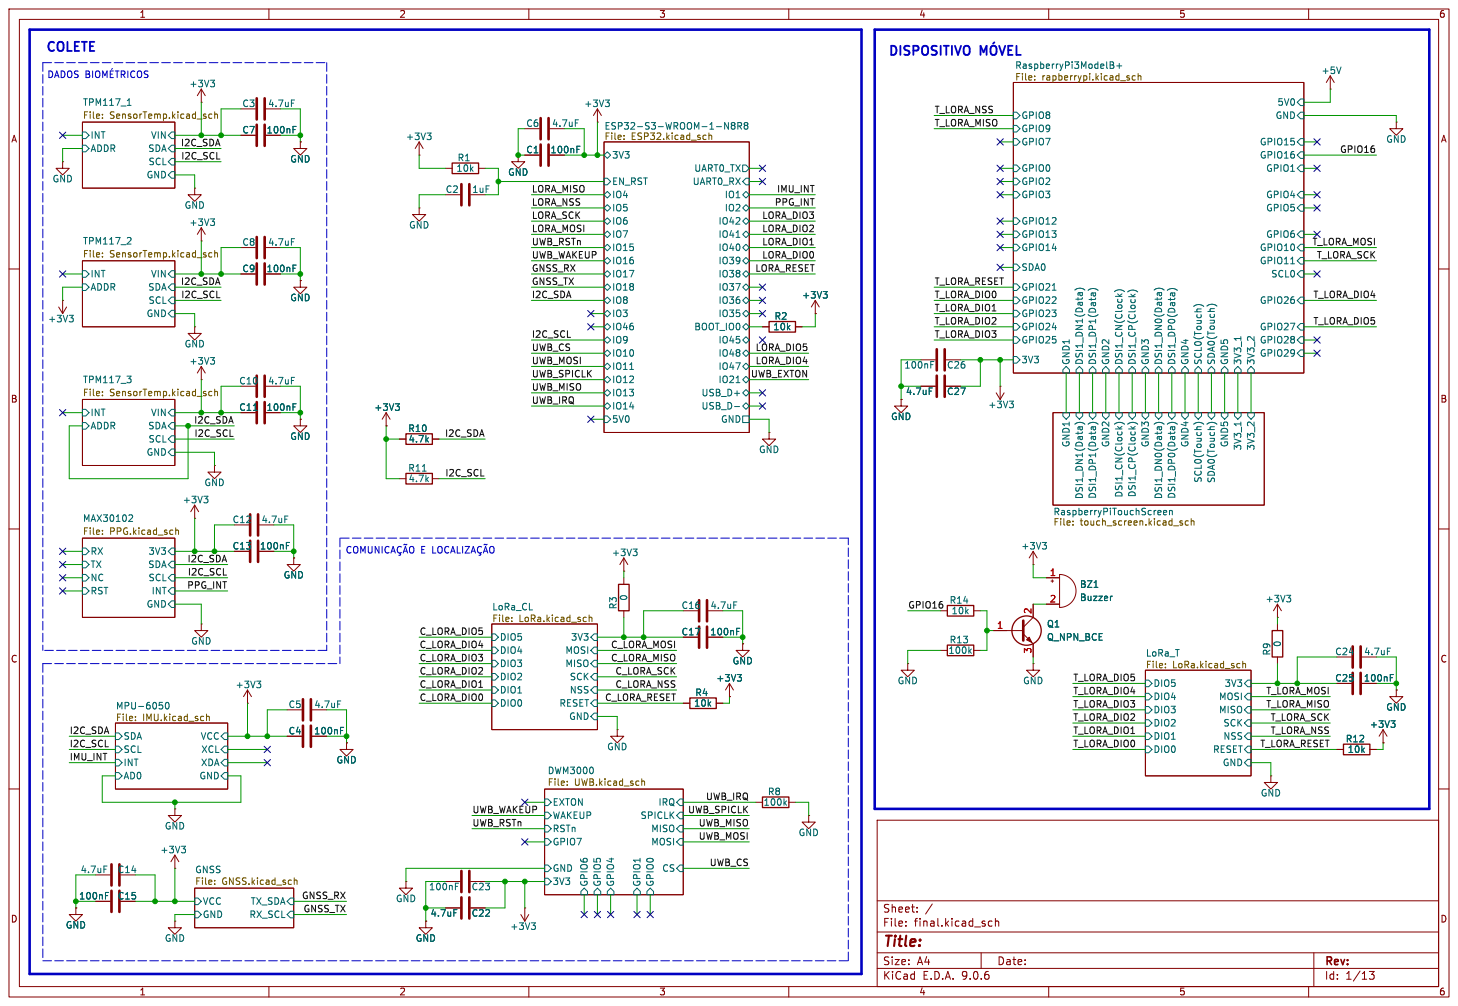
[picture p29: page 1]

5V0 GPIO1 GPIO4 GPIO10 GPIO26 GPIO15 GPIO5 SCL0 GPIO6 GPIO16 GPIO11 GPIO27 GPIO29 GPIO28 GND1 DSI1_DN1(Data) DSI1_DP1(Data) GND2 DSI1_CN(Clock) DSI1_CP(Clock) GND3 DSI1_DN0(Data) DSI1_DP0(Data) GND4 SCL0(Touch) SDA0(Touch) GND5 3V3_1 3V3_2

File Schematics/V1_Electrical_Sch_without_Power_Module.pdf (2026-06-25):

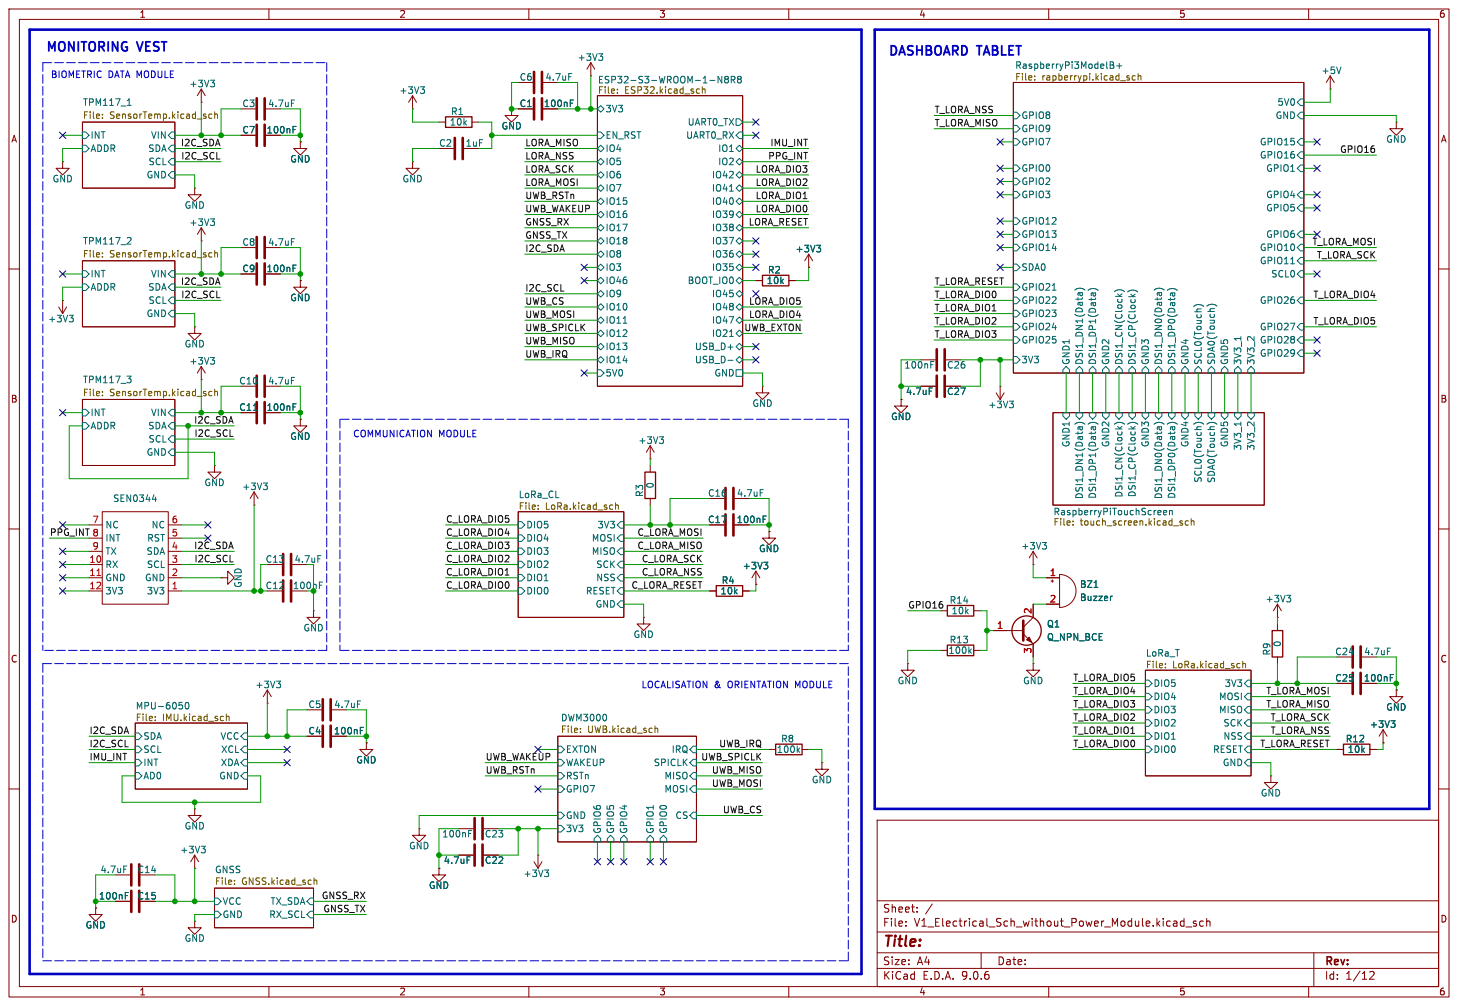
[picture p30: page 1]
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

100k 3V3 1 GND 2 SCL 3 SDA 4 RST 5 NC 6
INT MPU-6050 File: IMU.kicad_schGND

Id: 1/12 Title: File: V1_Electrical_Sch_without_Power_Module.kicad_sch Sheet: /

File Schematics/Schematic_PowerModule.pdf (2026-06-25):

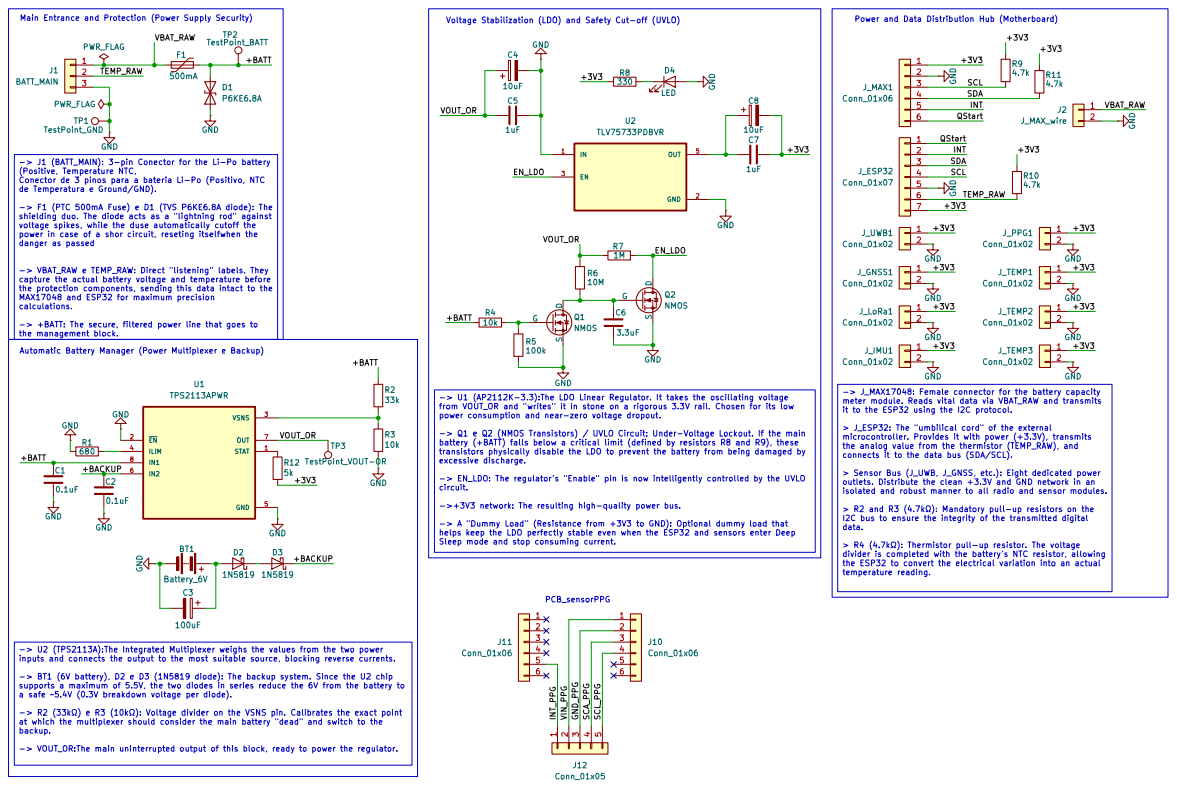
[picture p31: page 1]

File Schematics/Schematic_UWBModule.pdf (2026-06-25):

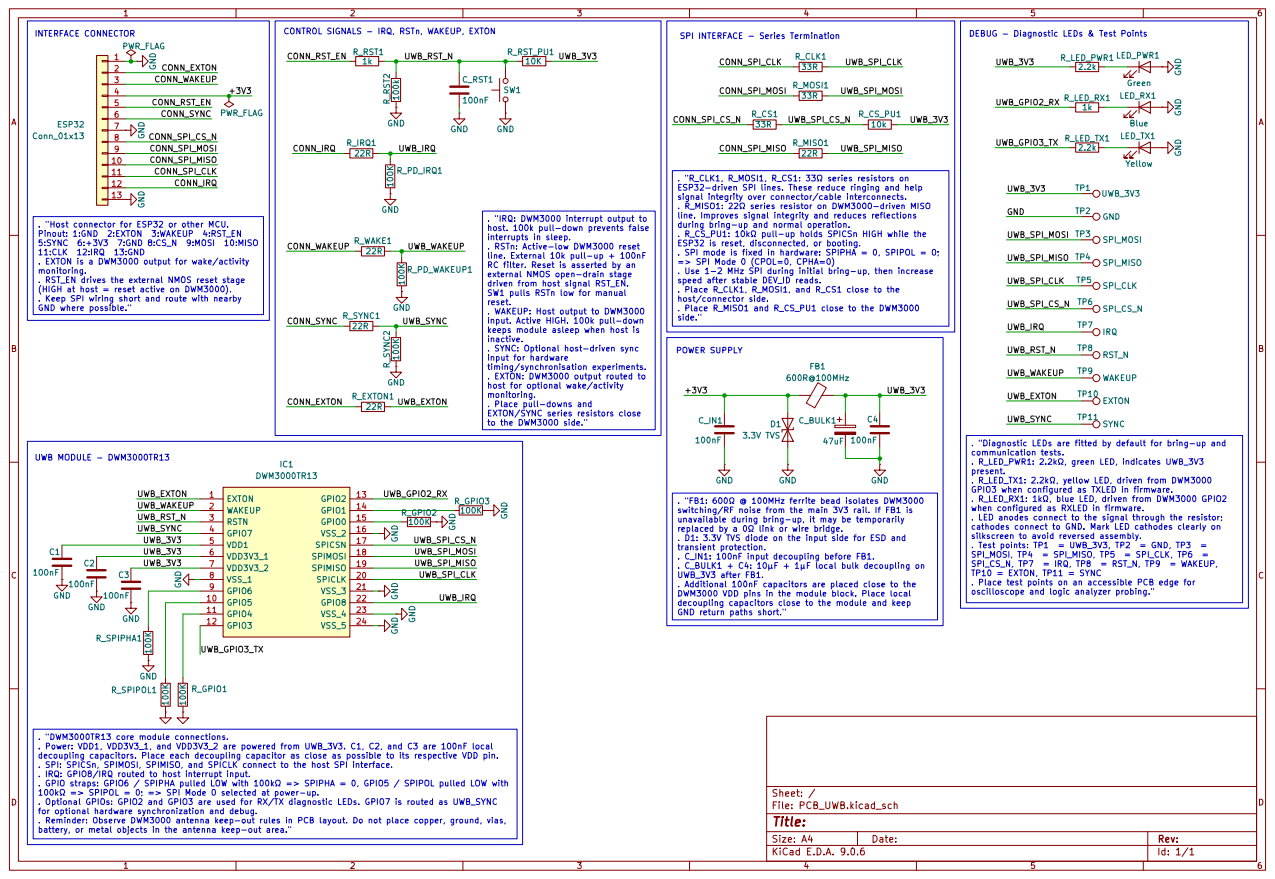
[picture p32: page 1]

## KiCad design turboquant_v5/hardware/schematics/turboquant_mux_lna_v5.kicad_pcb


Board: 4 copper layers, 100.0 x 80.0 mm, 25 parts (0 on the bottom side), 3 nets.

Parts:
F1: 2A; Fuse_1206_3216Metric
J1: 12V_Input; TerminalBlock_bornier-2_P5.08mm
J2: TX_BUS; SMA_EDGE
J3: E1_GPIO; PinHeader_2x10_P2.54mm_Vertical
J4: RX0_OUT; SMA_EDGE
J5: RX1_OUT; SMA_EDGE
Q9, Q10, Q11, Q12, Q13, Q14, Q15, Q16: IRF830; TO-220-3_Vertical
U1: LM7805; TO-252-2
U2: AMS1117-3.3; SOT-223-3_TabPin2
U3, U4: DG408; SOIC-16_3.9x9.9mm_P1.27mm
U5: 74HCT595; SOIC-16_3.9x9.9mm_P1.27mm
U6, U7: OPA1641; SOIC-8_3.9x4.9mm_P1.27mm
U8, U9, U10, U11: TC4427; SOIC-8_3.9x4.9mm_P1.27mm

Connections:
+5V: U1.3, U2.3
+12V: F1.1, F1.2, J1.1, U1.1
GND: J1.2, J2.2, J4.2, J5.2, U1.2, U2.1

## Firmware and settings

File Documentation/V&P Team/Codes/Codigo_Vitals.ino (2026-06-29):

#include <Wire.h>
#include <Adafruit_TMP117.h>
#include <Adafruit_Sensor.h>
#include <DFRobot_BloodOxygen_S.h>
#include <math.h>

// ========= CONFIGURAÇÕES DE PINOS =========
#define I2C_SDA 21
#define I2C_SCL 22
#define ALERT_PIN 27

// ========= CONSTANTES TMP117 =========
#define PERIOD_MS 10000UL
#define IGNORE_TIME_MS 180000UL 
#define MIN_THRESHOLD 2.0f
#define MAX_THRESHOLD 39.0f
#define CLOSE_PAIR_THRESHOLD 1.0f 
#define FAR_SENSOR_THRESHOLD 2.5f 
#define TMP117_ADDR_1 0x48
#define TMP117_ADDR_2 0x4A
#define TMP117_ADDR_3 0x4B

// ========= CONSTANTES PPG (MAX30102) =========
#define MAX_I2C_ADDRESS 0x57
const int SPO2_MIN_LIMIT = 92;
const int HR_MAX_LIMIT = 100;
const int HR_MIN_LIMIT = 60;

// ========= OBJETOS =========
Adafruit_TMP117 tmp1, tmp2, tmp3;
DFRobot_BloodOxygen_S_I2C MAX30102(&Wire, MAX_I2C_ADDRESS);

struct SensorNode {
  Adafruit_TMP117* dev;
  uint8_t addr;
  bool ok;
  float lastTemp;
};

SensorNode sensors[3] = {
  { &tmp1, TMP117_ADDR_1, false, NAN },
  { &tmp2, TMP117_ADDR_2, false, NAN },
  { &tmp3, TMP117_ADDR_3, false, NAN }
};

// ========= VARIÁVEIS GLOBAIS =========
volatile bool isrFlag = false;
unsigned long lastKick = 0;
unsigned long systemStartMs = 0;
unsigned long lastMaxRead = 0;
bool waitingForData = false;

// Variáveis TMP117
bool Flag_lowTemp = false, Flag_highTemp = false, Flag_faultySensor = false;
int faultySensorIndex = -1;
bool sensorIgnored[3] = { false, false, false };
unsigned long ignoreUntil[3] = { 0, 0, 0 };
uint32_t counter = 0;
float sumCalculatedMeans = 0.0f;
uint32_t numCalculatedMeans = 0;
float userTemperatureToSend = NAN;
bool userTemperatureReadyToSend = false;

// Variáveis PPG (Fluxograma)
int total_counter = 0;
int HR_counter = 0;
int SPO2_counter = 0;
long HR_total = 0;
long SPO2_total = 0;

// Variáveis para Média de 1 segundo (PPG)
unsigned long lastPPGSecond = 0;
long ppgHRSum = 0;
long ppgSPO2Sum = 0;
int ppgSampleCount = 0;

void IRAM_ATTR onAlert() {
  isrFlag = true;
}

// ========= FUNÇÕES AUXILIARES I2C =========
static bool readReg16(uint8_t a, uint8_t reg, uint16_t &v) {
  Wire.beginTransmission(a);
  Wire.write(reg);
  if (Wire.endTransmission(false) != 0) return false;
  if (Wire.requestFrom((int)a, 2) != 2) return false;
  v = ((uint16_t)Wire.read() << 8) | Wire.read();
  return true;
}

static bool writeReg16(uint8_t a, uint8_t reg, uint16_t v) {
  Wire.beginTransmission(a);
  Wire.write(reg);
  Wire.write((uint8_t)(v >> 8));
  Wire.write((uint8_t)(v & 0xFF));
  return Wire.endTransmission() == 0;
}

// ========= LÓGICA TMP117 (SEM ALTERAÇÃO) =========
bool initTMP117(SensorNode &s) {
  s.ok = s.dev->begin(s.addr, &Wire);
  Serial.printf("INIT | sensor_addr=0x%02X | status=%s\r\n", s.addr, s.ok ? "OK" : "FAIL");
  if (!s.ok) return false;
  s.dev->interruptsActiveLow(true);
  uint16_t cfg = 0;
  if (readReg16(s.addr, 0x01, cfg)) {
    cfg |= 0x0040;
    writeReg16(s.addr, 0x01, cfg);
    Serial.printf("CFG | sensor_addr=0x%02X | config=0x%04X\r\n", s.addr, cfg);
  }
  s.dev->setMeasurementMode(TMP117_MODE_SHUTDOWN);
  return true;
}

void kickAllSensors() {
  isrFlag = false;
  waitingForData = true;
  lastKick = millis();
  for (int i = 0; i < 3; i++) {
    if (sensors[i].ok) sensors[i].dev->setMeasurementMode(TMP117_MODE_ONE_SHOT);
  }
  Serial.printf("KICK | ms=%lu\r\n", lastKick);
}

void ignoreSensor(int idx, unsigned long now) {
  sensorIgnored[idx] = true;
  ignoreUntil[idx] = now + IGNORE_TIME_MS;
  Flag_faultySensor = true;
  faultySensorIndex = idx;
  Serial.printf("SENSOR_IGNORED | sensor_addr=0x%02X | ms=%lu | ignoreUntil=%lu\r\n", sensors[idx].addr, now, ignoreUntil[idx]);
}

bool faultySensorDetection(bool validMask[3], float temps[3], unsigned long now) {
  Flag_faultySensor = false;
  faultySensorIndex = -1;
  if (!validMask[0] || !validMask[1] || !validMask[2]) {
    Serial.println("FAULT_CHECK | status=SKIPPED | reason=not_all_sensors_available");
    return false;
  }
  float d_48_4A = fabs(temps[0] - temps[1]);
  float d_48_4B = fabs(temps[0] - temps[2]);
  float d_4A_4B = fabs(temps[1] - temps[2]);
  Serial.printf("FAULT_CHECK | d_48_4A=%.3f | d_48_4B=%.3f | d_4A_4B=%.3f\r\n", d_48_4A, d_48_4B, d_4A_4B);

  if (d_48_4A > FAR_SENSOR_THRESHOLD && d_4A_4B > FAR_SENSOR_THRESHOLD && d_48_4A > d_48_4B && d_4A_4B > d_48_4B) {
    validMask[1] = false; ignoreSensor(1, now);
    Serial.println("FAULT_DETECTED | faultySensor=0x4A");
    return true;
  }
  if (d_48_4B > CLOSE_PAIR_THRESHOLD) {
    if (d_48_4A > d_4A_4B) { validMask[0] = false; ignoreSensor(0, now); Serial.println("FAULT_DETECTED | faultySensor=0x48"); return true; }
    else if (d_4A_4B > d_48_4A) { validMask[2] = false; ignoreSensor(2, now); Serial.println("FAULT_DETECTED | faultySensor=0x4B"); return true; }
  }
  Serial.println("FAULT_DETECTED | faultySensor=NONE");
  return false;
}

// ========= SETUP =========
void setup() {
  Serial.begin(115200);
  delay(1500);
  Serial.println("START");
  Wire.begin(I2C_SDA, I2C_SCL);
  systemStartMs = millis();
  lastPPGSecond = millis();

  while (false == MAX30102.begin()) { Serial.println("ERR, init fail!"); delay(1000); }
  MAX30102.sensorStartCollect();

  initTMP117(sensors[0]);
  initTMP117(sensors[1]);
  initTMP117(sensors[2]);

  pinMode(ALERT_PIN, INPUT_PULLUP);
  attachInterrupt(digitalPinToInterrupt(ALERT_PIN), onAlert, FALLING);
  kickAllSensors();
}

// ========= LOOP =========
void loop() {
  unsigned long now = millis();

  // --- LÓGICA PPG (1 SEGUNDO + FLUXOGRAMA) ---
  if (isrFlag || (now - lastMaxRead > 200)) {
    if (isrFlag && !waitingForData) isrFlag = false;

    MAX30102.getHeartbeatSPO2();
    lastMaxRead = now;
    int spo2 = MAX30102._sHeartbeatSPO2.SPO2;
    int hr = MAX30102._sHeartbeatSPO2.Heartbeat;

    if (spo2 > 0) {
      // Acúmulo para a média de 1 segundo
      ppgHRSum += hr;
      ppgSPO2Sum += spo2;
      ppgSampleCount++;

      // Acúmulo para Fluxograma (60 amostras)
      total_counter++;
      if (hr != -1) { HR_counter++; HR_total += hr; }
      if (spo2 != -1) { SPO2_counter++; SPO2_total += spo2; }

      if (total_counter >= 60) {
        float HR_mean = (HR_counter > 0) ? (float)HR_total / HR_counter : 0;
        float SPO2_mean = (SPO2_counter > 0) ? (float)SPO2_total / SPO2_counter : 0;
        Serial.print("MEANS,"); Serial.print(SPO2_mean); Serial.print(","); Serial.println(HR_mean);

        if (SPO2_mean < SPO2_MIN_LIMIT) Serial.println("ALERT,SPO2_min");
        if (HR_mean > HR_MAX_LIMIT) Serial.println("ALERT,HR_max");
        else if (HR_mean < HR_MIN_LIMIT) Serial.println("ALERT,HR_min");

        total_counter = 0; HR_counter = 0; SPO2_counter = 0; HR_total = 0; SPO2_total = 0;
      }
    }
  }

  // Envio Periódico de 1 segundo (PPG)
  if (now - lastPPGSecond >= 1000) {
    if (ppgSampleCount > 0) {
      Serial.print("DATA,"); Serial.print(now); Serial.print(",");
      Serial.print(ppgSPO2Sum / ppgSampleCount); Serial.print(","); 
      Serial.println(ppgHRSum / ppgSampleCount);
    }
    ppgHRSum = 0; ppgSPO2Sum = 0; ppgSampleCount = 0;
    lastPPGSecond = now;
  }

  // --- LÓGICA TEMPERATURA (EXATAMENTE COMO SOLICITADO) ---
  if (!waitingForData && (now - lastKick >= PERIOD_MS)) {
    kickAllSensors();
  }

  if (waitingForData && (isrFlag || digitalRead(ALERT_PIN) == LOW)) {
    isrFlag = false;
    waitingForData = false;
    float mean = NAN; uint8_t validCount = 0;
    float temps[3] = { NAN, NAN, NAN };
    bool validMask[3] = { false, false, false };
    unsigned long tRead = millis();

    // Reativa sensores ignorados e lê dados
    for (int i = 0; i < 3; i++) {
      if (sensorIgnored[i] && tRead >= ignoreUntil[i]) {
        sensorIgnored[i] = false;
        Serial.printf("SENSOR_REACTIVATED | sensor_addr=0x%02X | ms=%lu\r\n", sensors[i].addr, tRead);
      }
      if (!sensors[i].ok) { sensors[i].lastTemp = NAN; continue; }
      sensors_event_t ev;
      sensors[i].dev->getEvent(&ev);
      sensors[i].lastTemp = ev.temperature;
      if (!isnan(ev.temperature) && !sensorIgnored[i]) { temps[i] = ev.temperature; validMask[i] = true; }
    }

    faultySensorDetection(validMask, temps, tRead);

    float sum = 0.0f;
    for (int i = 0; i < 3; i++) { if (validMask[i]) { sum += temps[i]; validCount++; } }

    if (validCount > 0) {
      mean = sum / validCount;
      // Impressão RAW (Como o código original apresentava)
      bool anyIgnored = sensorIgnored[0] || sensorIgnored[1] || sensorIgnored[2];
      Flag_faultySensor = anyIgnored;
      if (anyIgnored) { for(int i=0; i<3; i++) if(sensorIgnored[i]) faultySensorIndex = i; } else { faultySensorIndex = -1; }

      Serial.printf("RAW | ms=%lu", tRead);
      for (int i = 0; i < 3; i++) {
        Serial.printf(" | sensor_%d_addr=0x%02X", i + 1, sensors[i].addr);
        if (sensors[i].ok && !isnan(sensors[i].lastTemp)) Serial.printf(" | sensor_%d_temp=%.3f", i + 1, sensors[i].lastTemp);
        else Serial.print(" | sensor_%d_temp=NA");
        Serial.printf(" | sensor_%d_ignored=%d", i + 1, sensorIgnored[i]);
        if (sensorIgnored[i]) Serial.printf(" | sensor_%d_ignoreUntil=%lu", i + 1, ignoreUntil[i]);
      }
      Serial.printf(" | Flag_faultySensor=%d", Flag_faultySensor);
      if (faultySensorIndex >= 0) Serial.printf(" | faultySensor_addr=0x%02X", sensors[faultySensorIndex].addr);
      else Serial.print(" | faultySensor_addr=NONE");
      Serial.println();

      if ((tRead - systemStartMs) < IGNORE_TIME_MS) {
        Serial.printf("STARTUP_IGNORE | ms=%lu | mean=%.3f | validCount=%u | remainingMs=%lu\r\n", 
                      tRead, mean, validCount, IGNORE_TIME_MS - (tRead - systemStartMs));
      } else {
        // Algoritmo TMP117
        Flag_lowTemp = (mean < MIN_THRESHOLD);
        Flag_highTemp = (mean > MAX_THRESHOLD);
        counter++; sumCalculatedMeans += mean; numCalculatedMeans++;
        
        float sampleMean = sumCalculatedMeans / numCalculatedMeans;
        userTemperatureReadyToSend = false;
        if (counter % (60000UL / PERIOD_MS) == 0) {
          userTemperatureToSend = sampleMean;
          userTemperatureReadyToSend = true;
          Serial.printf("USER_TEMP_READY | ms=%lu | userTemperatureToSend=%.3f\r\n", tRead, userTemperatureToSend);
          sumCalculatedMeans = 0; numCalculatedMeans = 0;
        }
        Serial.printf("DATA | ms=%lu | mean=%.3f | validCount=%u | Flag_lowTemp=%d | Flag_highTemp=%d | Flag_faultySensor=%d | counter=%lu | sampleMean=%.3f | readyToSend=%d\r\n",
                      tRead, mean, validCount, Flag_lowTemp, Flag_highTemp, Flag_faultySensor, counter, sampleMean, userTemperatureReadyToSend);
      }
    }
  }
}

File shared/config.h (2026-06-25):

/**
 * @file config.h
 * @brief Ficheiro central de configurações de hardware e limites de segurança.
 * @details Contém o mapeamento de pinos (Pinout) para diferentes versões do ESP32,
 * endereços I2C dos periféricos, offsets de calibração do IMU e os limiares 
 * críticos (Thresholds) para acionamento de alarmes vitais e de queda.
 * @version 1.0
 * @date 2026
 * * @copyright Copyright (c) 2026
 */

#ifndef CONFIG_H
#define CONFIG_H

#include <Arduino.h>

/**
 * @brief Configuração de pinos
 *
 */

#define SPI_MISO    13      ///< Pino MISO para o barramento SPI (LoRa)
#define SPI_MOSI    11      ///< Pino MOSI para o barramento SPI (LoRa)
#define SPI_SCLK    12      ///< Pino Clock para o barramento SPI (LoRa)
#define SPI_NSS     10      ///< Pino Chip Select (CS/NSS) do módulo LoRa
#define DIO0        2       ///< Pino de interrupção (RX/TX Done) do módulo LoRa
#define NRESET      14      ///< Pino de hardware reset do módulo LoRa
#define I2C_SDA     4       ///< Pino de dados do barramento I2C (Sensores)
#define I2C_SCL     5       ///< Pino de clock do barramento I2C (Sensores)
#define ISR_PIN     9       ///< Pino genérico para interrupções externas de hardware
#define FSR_PIN     6       ///< Pino ADC para o sensor de força (Botão SOS)

/**
 * @brief Endereços hexadecimais nativos (ou configurados por hardware) dos sensores ResQSense.
 */
#define IMU_ADDR     0x68                   ///< Endereço do IMU (MPU-6050)
#define TMP_ADDR     0x48                   ///< Endereço do Sensor de Temperatura 1 (TMP117 Base)
#define TMPA_ADDR    0x4A                   ///< Endereço do Sensor de Temperatura 2 (TMP117 A)
#define TMPB_ADDR    0x4B                   ///< Endereço do Sensor de Temperatura 3 (TMP117 B)
#define MAX_ADDR     0x57                   ///< Endereço do Sensor Biométrico (MAX30102 Oximetria)
#define GNSS_ADDR    0x66                   ///< Endereço do Módulo de Localização GNSS

/**
 * @brief Constantes para conversão de valores RAW de 16-bits para unidades SI (g e º/s).
 */
#define IMU_ACCEL_SENSIVITY 2048.0f         ///< Fator de escala do Acelerómetro (16g = 2048 LSB/g)
#define IMU_GYRO_SENSIVITY  16.4f           ///< Fator de escala do Giroscópio (2000º/s = 16.4 LSB/º/s)
#define IMU_OFFSET_ACCEL_X  -372            ///< Offset estático de calibração para o eixo X (Aceleração)
#define IMU_OFFSET_ACCEL_Y  14              ///< Offset estático de calibração para o eixo Y (Aceleração)
#define IMU_OFFSET_ACCEL_Z  12              ///< Offset estático de calibração para o eixo Z (Aceleração)
#define IMU_OFFSET_GYRO_X   -42             ///< Offset estático de calibração para o eixo X (Giroscópio)
#define IMU_OFFSET_GYRO_Y   -8              ///< Offset estático de calibração para o eixo Y (Giroscópio)
#define IMU_OFFSET_GYRO_Z   -1              ///< Offset estático de calibração para o eixo Z (Giroscópio)
#define GRAVITY             9.81f           ///< Constante de aceleração gravítica na Terra (m/s²)

/**
 * @brief Limiares de Força e janelas de tempo para identificação de padrões de queda.
 * @note Os nomes das macros mantêm a nomenclatura original de implementação.
 */
#define TRESHOLD_FALL       0.52f           ///< Limiar máximo para deteção de Free-Fall (Aceleração < 0.52G)
#define TRESHOLD_IMPACT     3.66f           ///< Limiar mínimo para deteção de choque brusco no solo (> 3.66G)
#define TRESHOLD_GRAVITY    0.10f           ///< Margem de erro estática para avaliar imobilidade (orientação final)
#define FALL_TIMEOUT        3000            ///< Tempo limite para o impacto ocorrer após o free-fall (em ms)
#define INACTIVITY_TIME     1500            ///< Tempo em que a vítima deve permanecer imóvel para confirmar Man-Down (em ms)

/**
 * @brief Parâmetros de funcionamento e gatilhos de segurança para monitorização corporal.
 */
#define TEMP_SAMPLE_TIME_MS    10000UL      ///< Intervalo padrão de leitura dos sensores de temperatura (10s)
#define TEMP_MIN               2.0f         ///< Limite Crítico Inferior para despoletar Alerta de Hipotermia/Ambiente (ºC)
#define TEMP_MAX               39.0f        ///< Limite Crítico Superior para despoletar Alerta de Febre/Exaustão (ºC)
#define IGNORE_SENSOR_INTERVAL 180000UL     ///< Tempo de Quarentena em que um sensor avariado fica na Blacklist (3 min)
#define CLOSE_PAIR_THRESHOLD   1.0f         ///< Desvio máximo tolerado entre dois sensores considerados próximos (ºC)
#define FAR_SENSOR_THRESHOLD   2.5f         ///< Desvio máximo tolerado para considerar uma leitura como discrepante (ºC)
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

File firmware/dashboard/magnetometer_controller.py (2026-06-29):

import math
import os
import threading
import time


class MagnetometerController:
    """
    Leitor de "heading" (rumo) para Raspberry Pi via I2C usando um MPU-6050.

    ATENCAO: o MPU-6050 e um sensor de 6 eixos (acelerometro + giroscopio) e
    NAO tem magnetometro. Por isso nao existe um Norte absoluto como no BNO08x
    antigo. Aqui o heading e RELATIVO: comeca em 0 graus quando o programa
    arranca e gira conforme voce roda fisicamente o sensor, integrando a
    velocidade angular do eixo Z do giroscopio.

    Resultado pratico: o radar gira quando voce roda o sensor, que e
    exactamente o comportamento pedido.

    Interface mantida identica ao controller anterior para nao mexer no
    testedashboard.py:
        - available()
        - start() / stop()
        - get_heading_degrees() / get_heading_radians()

    Ligacoes (as MESMAS do sensor antigo, I2C padrao do Raspberry Pi):
        Pino 1  (3.3V) -> VCC
        Pino 9  (GND)  -> GND
        Pino 3  (SDA)  -> SDA
        Pino 5  (SCL)  -> SCL
    """

    # Registos do MPU-6050
    _PWR_MGMT_1 = 0x6B
    _WHO_AM_I = 0x75
    _GYRO_CONFIG = 0x1B
    _GYRO_ZOUT_H = 0x47
    # Sensibilidade do giroscopio em ±250 graus/s (FS_SEL = 0): 131 LSB por (graus/s)
    _GYRO_SENS_250DPS = 131.0

    def __init__(self, update_interval_sec=0.02):
        self.backend = None
        self.bus = None
        self.address = None
        self.running = False
        self.thread = None
        # Atualizacao rapida (50 Hz) para integrar o giroscopio com pouco erro.
        self.update_interval_sec = update_interval_sec
        self.heading_deg = 0.0
        self.gyro_bias_z = 0.0
        self.last_error = None
        self._lock = threading.RLock()
        self._last_time = None

        # Offset inicial do rumo (graus) e sentido de rotacao, configuraveis.
        try:
            self.offset_deg = float(os.getenv("RESQSENSE_MAG_OFFSET_DEG", "0"))
        except ValueError:
            self.offset_deg = 0.0

        self.z_sign = -1.0 if os.getenv("RESQSENSE_MAG_Z_SIGN", "1").strip() == "-1" else 1.0

        try:
            self.i2c_bus_num = int(os.getenv("RESQSENSE_MPU_I2C_BUS", "1"))
        except ValueError:
            self.i2c_bus_num = 1

        try:
            self.address = int(os.getenv("RESQSENSE_MPU_I2C_ADDR", "0x68"), 0)
        except ValueError:
            self.address = 0x68

        self.heading_deg = self.offset_deg % 360.0

        try:
            try:
                from smbus2 import SMBus  # type: ignore
            except ImportError:
                from smbus import SMBus  # type: ignore

            bus = SMBus(self.i2c_bus_num)

            # Confirma que ha um MPU-6050/6500 no endereco esperado.
            who = bus.read_byte_data(self.address, self._WHO_AM_I)
            if who not in (0x68, 0x70, 0x72, 0x73, 0x71):
                # Continua mesmo assim, mas regista o aviso.
                self.last_error = f"WHO_AM_I inesperado: 0x{who:02X}"

            # Acorda o sensor (sai do modo sleep).
            bus.write_byte_data(self.address, self._PWR_MGMT_1, 0x00)
            time.sleep(0.05)
            # Garante faixa do giroscopio em ±250 dps.
            bus.write_byte_data(self.address, self._GYRO_CONFIG, 0x00)
            time.sleep(0.05)

            self.bus = bus
            self.backend = "mpu6050"

            # Calibra o bias do giroscopio com o sensor parado.
            self._calibrate_gyro_bias()
        except Exception as exc:
            self.last_error = str(exc)
            self.backend = None
            self.bus = None

    # ------------------------------------------------------------------ #
    # API publica (igual ao controller antigo)
    # ------------------------------------------------------------------ #
    def available(self):
        return self.backend is not None and self.bus is not None

    def start(self):
        if not self.available() or self.running:
            return
        self.running = True
        self._last_time = time.monotonic()
        self.thread = threading.Thread(target=self._worker, daemon=True)
        self.thread.start()

    def stop(self):
        self.running = False
        if self.thread and self.thread.is_alive():
            self.thread.join(timeout=1.0)
        self.thread = None

    def get_heading_degrees(self):
        with self._lock:
            return self.heading_deg

    def get_heading_radians(self):
        return math.radians(self.get_heading_degrees())

    def reset_heading(self, value_deg=0.0):
        """Zera (ou define) o rumo atual. Util para 'apontar o radar' a frente."""
        with self._lock:
            self.heading_deg = value_deg % 360.0

    # ------------------------------------------------------------------ #
    # Internos
    # ------------------------------------------------------------------ #
    def _read_word_signed(self, reg_high):
        high = self.bus.read_byte_data(self.address, reg_high)
        low = self.bus.read_byte_data(self.address, reg_high + 1)
        value = (high << 8) | low
        if value >= 0x8000:
            value -= 0x10000
        return value

    def _read_gyro_z_dps(self):
        raw = self._read_word_signed(self._GYRO_ZOUT_H)
        return raw / self._GYRO_SENS_250DPS

    def _calibrate_gyro_bias(self, samples=200):
        """Mede o desvio do giroscopio parado para reduzir a deriva (drift)."""
        try:
            total = 0.0
            for _ in range(samples):
                total += self._read_gyro_z_dps()
                time.sleep(0.002)
            self.gyro_bias_z = total / samples
        except Exception as exc:
            self.last_error = str(exc)
            self.gyro_bias_z = 0.0

    def _normalize_heading(self, heading_deg):
        return (heading_deg + 360.0) % 360.0

    def _worker(self):
        while self.running:
            try:
                now = time.monotonic()
                dt = now - (self._last_time or now)
                self._last_time = now
                if dt <= 0 or dt > 1.0:
                    # Salto de tempo invalido: ignora esta iteracao.
                    time.sleep(self.update_interval_sec)
                    continue

                rate_dps = (self._read_gyro_z_dps() - self.gyro_bias_z) * self.z_sign
                with self._lock:
                    self.heading_deg = self._normalize_heading(
                        self.heading_deg + rate_dps * dt
                    )
            except Exception as exc:
                self.last_error = str(exc)
            time.sleep(self.update_interval_sec)

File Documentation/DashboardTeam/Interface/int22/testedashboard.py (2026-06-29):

import tkinter as tk
from tkinter import ttk, messagebox
import datetime
import math
import os
import random
import time

# IMPORTAÃ‡ÃƒO DOS OUTROS SCRIPTS
from models import DashboardController, Operator
from simulation import HardwareSimulator
from autocomplete_entry import AutocompleteEntry
from firestation_database import get_fire_station_names
from buzzer_controller import BuzzerController
from magnetometer_controller import MagnetometerController
from speaker_controller import SpeakerController
from telemetry_protocol import UARTTelemetryReceiver

from language_config import LANGUAGE_OPTIONS, get_language_label, translate
import threading
from sync_postgresql import sincronizar_para_postgresql

class ResQSenseApp:
    def __init__(self, root):
        self.root = root
        self.root.title("ResQSense.exe")

        # Ajusta automaticamente ao ecra (importante para Raspberry Pi 800x480)
        screen_w = self.root.winfo_screenwidth()
        screen_h = self.root.winfo_screenheight()
        window_w = min(1000, max(760, screen_w - 40))
        window_h = min(600, max(460, screen_h - 80))
        window_w = min(window_w, screen_w)
        window_h = min(window_h, screen_h)
        pos_x = max(0, (screen_w - window_w) // 2)
        pos_y = max(0, (screen_h - window_h) // 2)
        self.root.geometry(f"{window_w}x{window_h}+{pos_x}+{pos_y}")
        self.root.minsize(min(760, window_w), min(460, window_h))
        self.root.protocol("WM_DELETE_WINDOW", self.on_close)

        # Inicializa o speaker passivo por software no GPIO 17.
        try:
            speaker_pin = int(os.getenv("RESQSENSE_SPEAKER_PIN", "17"))
        except ValueError:
            speaker_pin = 17
        self.speaker = SpeakerController(pin=speaker_pin)
        self.buzzer = None
        if not self.speaker.available():
            self.buzzer = BuzzerController(pin=17)
        self.magnetometer = MagnetometerController(update_interval_sec=0.15)
        self.magnetometer.start()
        
        # INICIALIZA O CONTROLADOR (BACKEND)
        self.controller = DashboardController()
        
        # Cores baseadas no wireframe original
        self.bg_color = "#d9d9d9"
        self.header_color = "#d9d9d9"
        self.sidebar_color = "#d9d9d9"
        self.alert_color = "#e74c3c" # Vermelho para alertas
        self.safe_color = "#2ecc71"  # Verde para seguro
        self.avatar_fill = "white"   # Cor de preenchimento do boneco
        self.avatar_outline = "black"
        
        self.root.configure(bg=self.bg_color)
        
        self.team_leader_name = ""
        self.fire_station_name = ""
        self.max_operationals = 5
        self.radar_ring_count = 5
        self.radar_ring_step_m = 40
        self.radar_max_distance_m = self.radar_ring_count * self.radar_ring_step_m
        
        # Lista HÃ­brida: { "id": "1", "name": "...", "angle": 0.0, "dist": 0.5, "logic_ref": OperatorObject, "is_leader": False }
        self.firefighters = []

        # Estado da aplicaÃ§Ã£o
        self.edit_mode = False 
        self.menu_open = False 
        self.blink_state = False 
        self.active_critical_signatures = set()
        self.pending_man_down_alerts = []
        self.warning_history = []
        self.current_alert_popup = None
        self.current_popup_data = None
        self.selected_firefighter_id = None
        self.session_panel_visible = False
        self.session_info_panel = None
        self.session_name_label = None
        self.dashboard_active = False
        self.simulation_job = None
        self.current_language = "en"
        self.language_window = None
        self.active_input_widget = None
        self.firefighter_touch_last_y = None
        self.firefighter_touch_dragging = False
        self.firefighter_touch_clear_job = None
        self.telemetry_receiver = None
        self.live_data_enabled = False
        ports_env = os.getenv("RESQSENSE_UART_PORTS", "").strip()
        if ports_env:
            self.live_data_ports = [part.strip() for part in ports_env.split(",") if part.strip()]
        else:
            single_port = os.getenv("RESQSENSE_UART_PORT", "/dev/cu.usbserial-10").strip()
            self.live_data_ports = [single_port] if single_port else ["/dev/cu.usbserial-10"]
        try:
            self.live_data_baudrate = int(os.getenv("RESQSENSE_UART_BAUD", "115200"))
        except ValueError:
            self.live_data_baudrate = 115200
        try:
            self.signal_loss_timeout_sec = float(os.getenv("RESQSENSE_SIGNAL_LOSS_TIMEOUT", "15"))
        except ValueError:
            self.signal_loss_timeout_sec = 15.0
        self.force_simulation_mode = os.getenv("RESQSENSE_FORCE_SIMULATION", "1").strip() != "0"
        leader_vest_env = os.getenv("RESQSENSE_LEADER_VEST_ID", "").strip()
        self.leader_vest_id = leader_vest_env if leader_vest_env else None
        self.radar_origin = None
        self.last_heading_deg = 0.0

        self.login_station_label = None
        self.login_name_label = None
        self.login_ops_label = None
        self.login_button = None
        self.sidebar_title_label = None
        self.menu_edit_button = None
        self.menu_resources_button = None
        self.menu_language_button = None
        self.end_session_button = None
        self.add_operational_button = None

        # Inicia com a tela de Login
        self.show_login_screen()

    def clear_window(self):
        """Limpa todos os widgets da janela atual"""
        self.close_language_window()
        self.active_input_widget = None
        for widget in self.root.winfo_children():
            widget.destroy()

    def t(self, key, **kwargs):
        return translate(self.current_language, key, **kwargs)

    def get_language_name(self, code=None):
        selected = code if code else self.current_language
        return get_language_label(selected)

    def set_language(self, language_code):
        valid_codes = {code for _, code in LANGUAGE_OPTIONS}
        if language_code not in valid_codes:
            return

        self.current_language = language_code

        if self.menu_open:
            self.menu_frame.place_forget()
            self.menu_open = False

        self.apply_translations_to_visible_widgets()
        self.refresh_sidebar_list_safe()
        self.draw_radar_safe()

    def apply_translations_to_visible_widgets(self):
        if self.login_station_label and self.login_station_label.winfo_exists():
            self.login_station_label.config(text=self.t("fire_station"))
        if self.login_name_label and self.login_name_label.winfo_exists():
            self.login_name_label.config(text=self.t("name_id"))
        if self.login_ops_label and self.login_ops_label.winfo_exists():
            self.login_ops_label.config(text=self.t("nr_operationals"))
        if self.login_button and self.login_button.winfo_exists():
            self.login_button.config(text=self.t("login"))
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

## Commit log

2026-05-12 Vital sensors example added
2026-05-12 First Test : IMU
2026-05-13 Defines for various boards use
2026-05-13 IMU Read with Tasks
2026-05-16 Sensor Library new things and start of mutex and tasks
2026-06-25 Docs and Schematics
2026-06-26 Final Schematics
    [ESP32-S3-WROOM-1-N8R8.kicad_sch, ESP32.kicad_sch, ESP32_module.kicad_sch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]
2026-06-29 Documentation Update
    [ecraTatil.kicad_pcb, ecraTatil.kicad_sch]
2026-06-29 Final Updates
    [DesignConstraints.xlsx, ResQSense - Viabilidade Económica V_Melhorada (n finalizado).xlsx, ResQSense - Viabilidade Económica.xlsx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]
